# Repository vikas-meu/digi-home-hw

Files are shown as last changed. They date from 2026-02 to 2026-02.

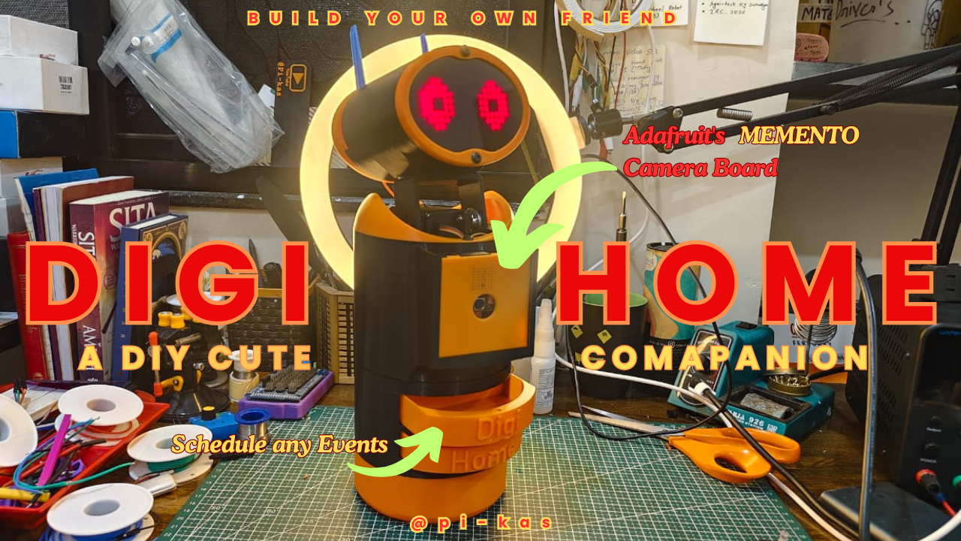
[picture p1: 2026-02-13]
Digi_Home.png

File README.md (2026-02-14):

# 🤖 Digi-Home: Smart Assistant & Memento Board




> **A futuristic, interactive home automation assistant powered by Arduino and ESP32.**  
> *Transform your space with animatronic expressions, IoT control, and automated dispensing.*

---

## 📖 Overview

**Digi-Home** is an integrated ecosystem that combines animatronics, IoT home automation, and interactive robotics. It utilizes a powerful Master-Slave architecture to manage home appliances, provide visual feedback through an animated head, and perform physical tasks like dispensing items.

**(image={System Overview Diagram showing the connections between ESP32, Arduino Base, and Arduino Head})**

### 🚀 Key Features
*   **Animatronic Head**: Expressive 8x8 Matrix eyes and servo-controlled eyelids.
*   **Smart Home Hub**: Web-based control for high-voltage appliances (Lights, Fans).
*   **Automated Dispenser**: Dual servo mechanisms for dispensing tasks.
*   **Interactive Modes**: Includes Dance, Security Sweep, and Sleep modes.

---

## 🛠️ Bill of Materials (BOM)

| Component | Qty | Purchase Link |
| :--- | :---: | :--- |
| **Memento Board By Adafruit** | 1 | [Buy Here](https://www.digikey.in/en/products/detail/adafruit-industries-llc/5420/24713460) |
| **LM2596S DC-DC Buck Converter Power Supply (12v to 5 v)** | 1 | [Buy Here](https://www.google.com/aclk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) |
| **LED 8X8 Matrix** | 2 | [Buy Here](https://www.google.com/aclk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) |
| **MG995 Servo Motor (for Neck)** | 2 | [Buy Here](https://www.google.com/aclk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) |
| **MG90S Servo Motor (for Antenna & Dispensor)** | 4 | [Buy Here](https://www.google.com/aclk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) |
| **Arduino nano (to expand Pins)** | 2 | [Buy Here](https://www.google.com/aclk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) |
| **24 Awg Wires bundle 5 meter** | 1 | [Buy Here](https://www.google.com/aclk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) |
| **eSun PLA+ 1.75mm (Color depends on your Choice)** | 1 | [Buy Here](https://www.google.com/aclk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) |
| **Soldering Iron (Recommended all Tools Are included in this))** | 1 | [Buy Here](https://www.google.com/aclk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) |
| **Glue Gun** | 1 | [Buy Here](https://www.meesho.com/glue-guns/pl/997?srsltid=AfmBOor-x8Y_ux-g0ucn7r0g1IZt1v4XrUss-9I_4eg-g9kcGDKD0NQX) |
| **ESP32 Wroom DA** | 1 | [Buy Here](https://robu.in/product/esp-wroom-32-esp32-wifi-bt-ble-mcu-module/) |
| **4 Channel Relay (5v)** | 1 | [Buy Here](https://www.google.com/aclk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) |
| **li-ion Battery Pack (12v) Recommended** | 1 | [Buy Here](https://www.google.com/aclk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) |
| **Wall Adapter (5V 4amp)** | 1 | [Buy Here](https://www.google.com/aclk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) |
| **Screw Driver Set** | 1 | [Buy Here](https://www.google.com/aclk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) |
| **Wire Cutter** | 1 | [Buy Here](https://kitsguru.com/products/economy-precision-flush-cutter-pcb-wire-nipper-cutting-tool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) |
| **DT830D Multimeter** | 1 | [Buy Here](https://robu.in/product/digital-multimeter-small-yellow-color-lcd-ac-dc-measuring-voltage-current/) |
| **M4x8mm Screws** | 8 | [Buy Here](https://www.google.com/aclk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) |

---

## 📚 Software Infrastructure & Libraries

To compile and upload the code, you **must** install the following libraries in your Arduino IDE.

### 1. Required Libraries
| Library Name | Purpose | Implementation |
| :--- | :--- | :--- |
| **MD_MAX72XX** | Handles the 8x8 LED Matrix display for the eyes. | `head_arduino_0x09.ino` |
| **Servo** | Controls the PWM signals for neck and dispenser motors. | All modules |
| **Wire** | Enables I2C communication between the Master and Slaves. | `Base` & `Head` |
| **WiFi & WebServer** | Enables ESP32 to act as a local IoT server. | `esp32_relay_module.ino` |

### 2. Step-by-Step Installation
1.  Open **Arduino IDE**.
2.  Go to **Tools** -> **Manage Libraries...** 
3.  In the search bar, type `MD_MAX72XX` and click **Install**.
4.  The `Servo`, `Wire`, `WiFi`, and `WebServer` libraries are usually built-in. If missing, search for them individually and install the versions by **Arduino** or **Espressif**.
5.  **ESP32 Board Support**: 
    - Go to `File` -> `Preferences`.
    - In "Additional Boards Manager URLs", paste: `https://raw.githubusercontent.com/espressif/arduino-esp32/gh-pages/package_esp32_index.json`.
    - Go to `Tools` -> `Board` -> `Boards Manager`, search for `esp32` and install.

---

## 🧠 Deep Dive: How the Code Works

The project is split into three core logic modules that communicate over a shared **I2C Bus**.

### 1. Base Controller (`0x08.ino`)
*   **The Logic**: Acts as the "Motor Cortex." It manages physical movement and timing.
*   **Movement Engine**: Uses a smoothing algorithm (`currentPos += (target - currentPos) * 0.1`) to ensure the neck doesn't snap abruptly, creating "alive-like" idle motions.
*   **Dispensing System**: A simple loop blocks I2C for a few seconds during a dispense cycle to ensure mechanical accuracy.

### 2. Head Controller (`0x09.ino`)
*   **The Logic**: Acts as the "Emotional Engine." It translates byte-arrays into facial expressions.
*   **Eye Patterns**: Expressions like `SAD`, `HAPPY`, and `SECURE` are stored as 8-byte hexadecimal arrays. The code updates these columns at high speed to create animations.
*   **Blink Logic**: A randomized timer triggers a "closed eye" pattern for 150ms every 2-5 seconds, simulating human-like behavior.

### 3. ESP32 Relay Module (`esp32_relay.ino`)
*   **The Logic**: Acts as the "Communication Gateway."
*   **REST API**: It maps specific URL paths (like `/light_on`) to GPIO toggles. When you visit the IP address, it serves a lightweight HTML page with buttons that trigger these endpoints.

---

## 🚀 Step-by-Step Setup & Upload

### Phase 1: Preparation
1.  **Wiring**: Connect all SDA pins together and all SCL pins together. Ensure a **Common Ground** between the Nano and ESP32.
2.  **Power**: Plug your 12V battery into the Buck Converter. Tune the converter to exactly **5.0V** before connecting to the Arduinos.

### Phase 2: Uploading Code
1.  **Base (Nano #1)**:
    - Open `Base_trigger.ino`.
    - Select Board: `Arduino Nano` (Processor: `ATmega328P (Old Bootloader)` is common).
    - Upload. Note: This device sits at I2C address `0x08`.
2.  **Head (Nano #2)**:
    - Open `head_arduino_0x09.ino`.
    - Upload to the second Nano. This device sits at I2C address `0x09`.
3.  **IoT Hub (ESP32)**:
    - Open `esp32_relay_module.ino`.
    - **Crucial**: Change lines 4 & 5 to your WiFi Name and Password.
    - Select Board: `ESP32 Dev Module`.
    - Upload. Open the Serial Monitor at 115200 baud to find the **IP Address**.

---

## 🐛 Troubleshooting & Common Errors

### 1. Hardware Issues
*   **"Servos are twitching or the board resets when they move"**
    - **Cause**: Current starvation. Servos can pull 1A+ each when stalled.
    - **Fix**: Use a dedicated 5V 4A supply. Do NOT power servos from the Nano's 5V pin.
*   **"I2C devices not found or data is corrupted"**
    - **Cause**: Missing pull-up resistors or floating ground.
    - **Fix**: Ensure GND is shared. Add two 4.7kΩ resistors between SDA-5V and SCL-5V if the bus is long.

### 2. Software Issues
*   **"Matrix is showing garbage or mirrored text"**
    - **Cause**: Incorrect `HARDWARE_TYPE`.
    - **Fix**: In `head_arduino_0x09.ino`, change `FC16_HW` to `GENERIC_HW` or `ICSTATION_HW` until it looks correct.
*   **"ESP32 won't connect to WiFi"**
    - **Cause**: 5GHz network or wrong credentials.
    - **Fix**: Ensure your router supports 2.4GHz. Triple-check the password in the code.

### 3. Logic Errors
*   **"Dispenser moves but doesn't stop"**
    - **Cause**: Potentiometer setting in MG90S (if modified) or logic interference.
    - **Fix**: Check `DISP_MIN` and `DISP_MAX` values in `Base_trigger.ino`.

---

> **Built with ❤️ for the Memento Board By Adafruit Project**  
> (image={Final assembly photo of the Digi-Home system})

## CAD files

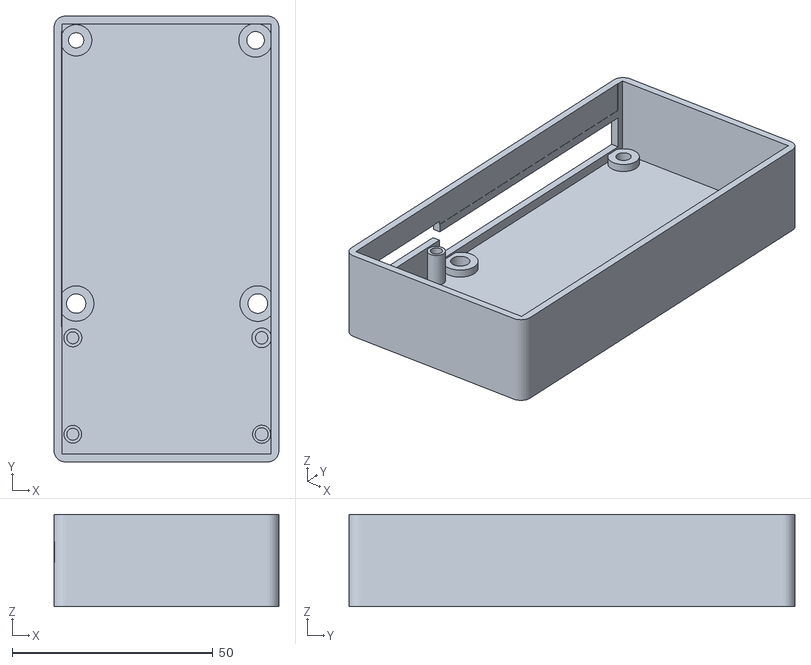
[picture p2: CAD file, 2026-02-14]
3d_files/Optional device cad here/relay_top.stl
56.0 x 111.0 x 23.0

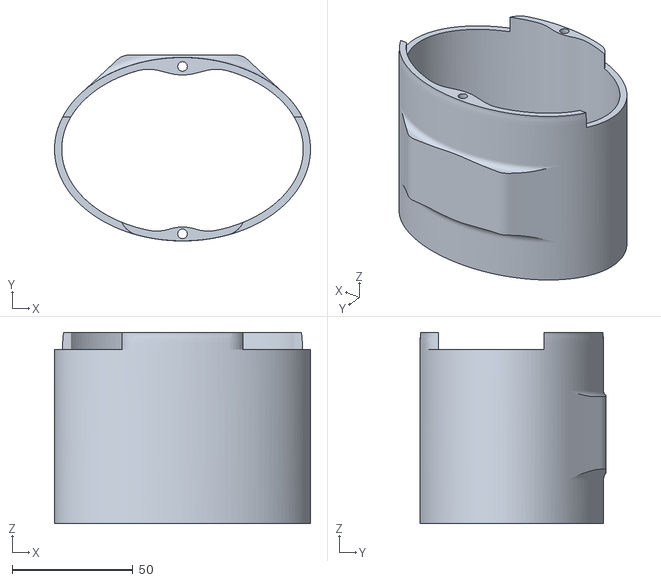
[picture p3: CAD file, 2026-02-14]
3d_files/part1_head_part/b.stl
106.0 x 77.0 x 79.2

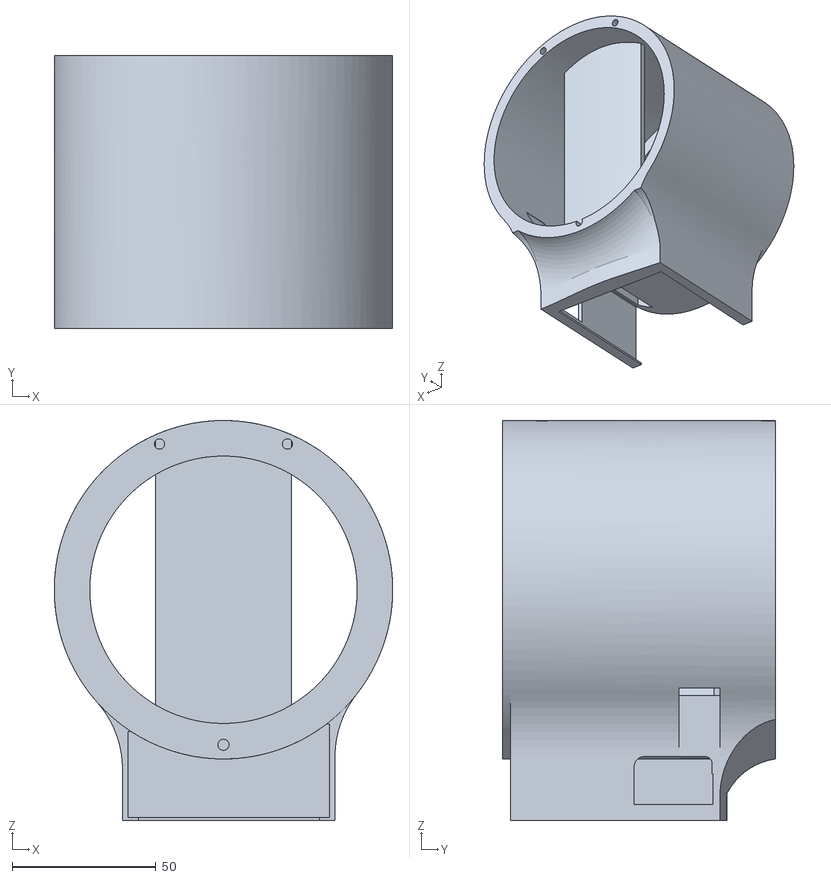
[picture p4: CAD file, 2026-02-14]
3d_files/part2_mid_section/i.stl
117.9 x 95.0 x 139.3

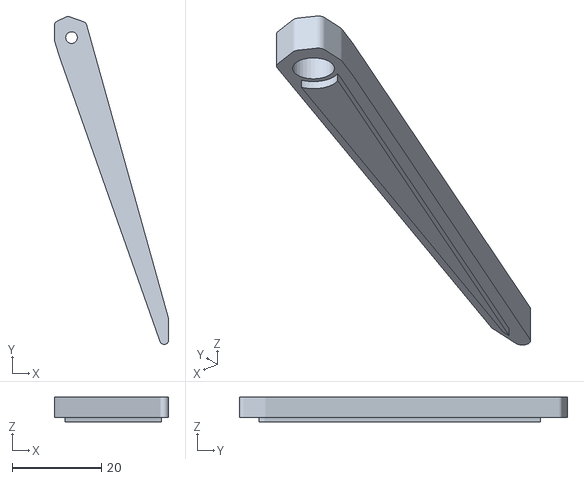
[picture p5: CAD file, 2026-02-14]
3d_files/part3_base_part/antenna_02.stl
25.6 x 73.5 x 5.50

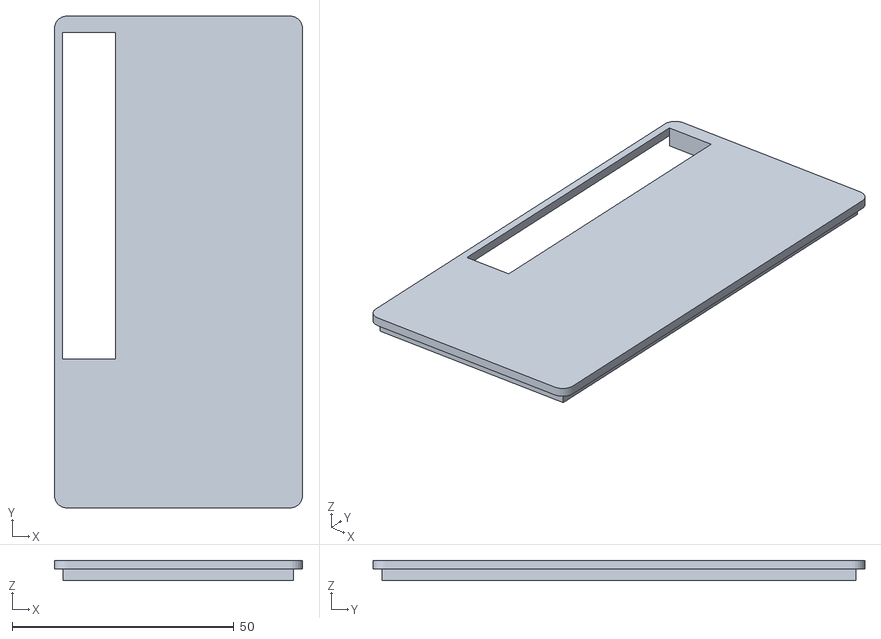
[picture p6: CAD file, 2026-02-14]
3d_files/Optional device cad here/relay_bottom.stl
56.0 x 111.0 x 4.62

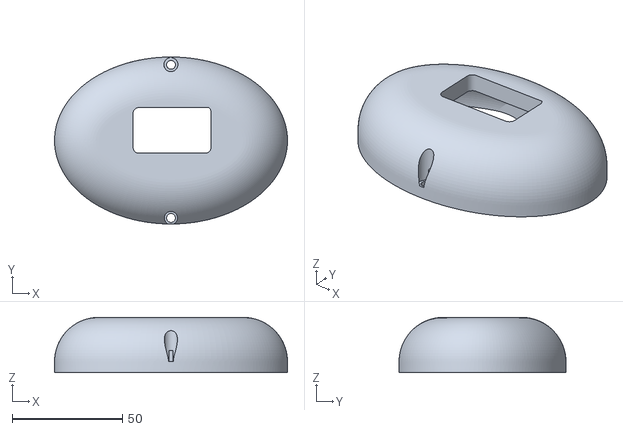
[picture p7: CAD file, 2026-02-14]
3d_files/part1_head_part/c.stl
105.5 x 75.6 x 25.0

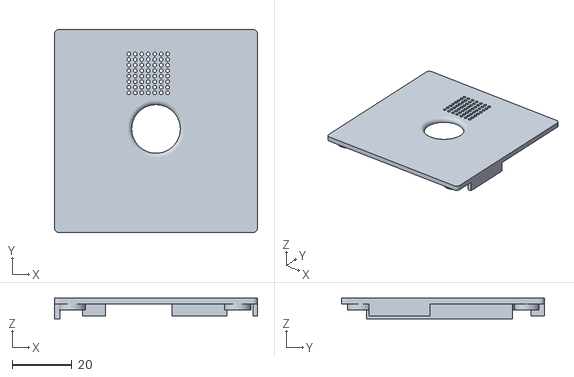
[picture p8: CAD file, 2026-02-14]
3d_files/part2_mid_section/memento_cover_top.stl
68.1 x 68.1 x 7.00

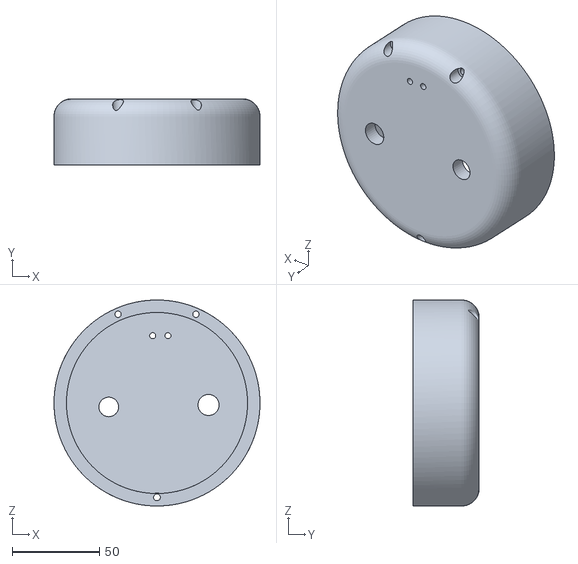
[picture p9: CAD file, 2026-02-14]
3d_files/part3_base_part/l.stl
117.9 x 38.0 x 117.9

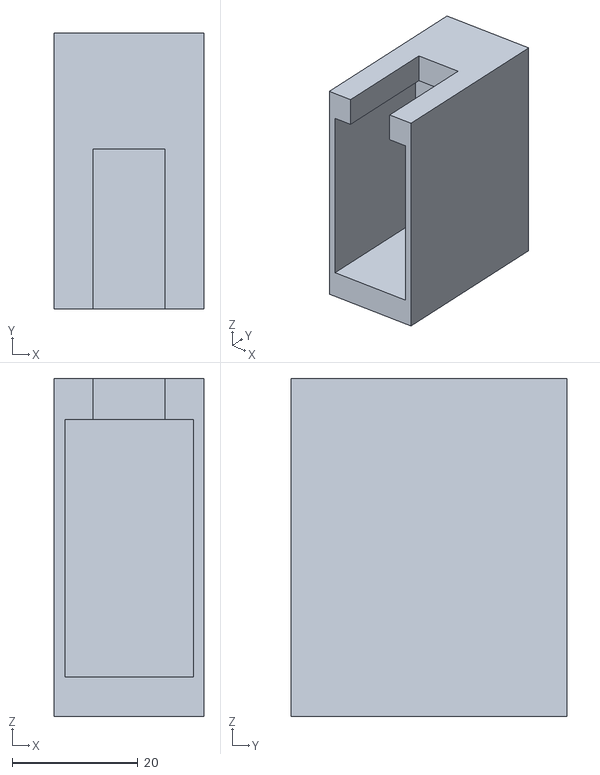
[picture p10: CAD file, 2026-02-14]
3d_files/part1_head_part/g.stl
23.8 x 44.0 x 53.8

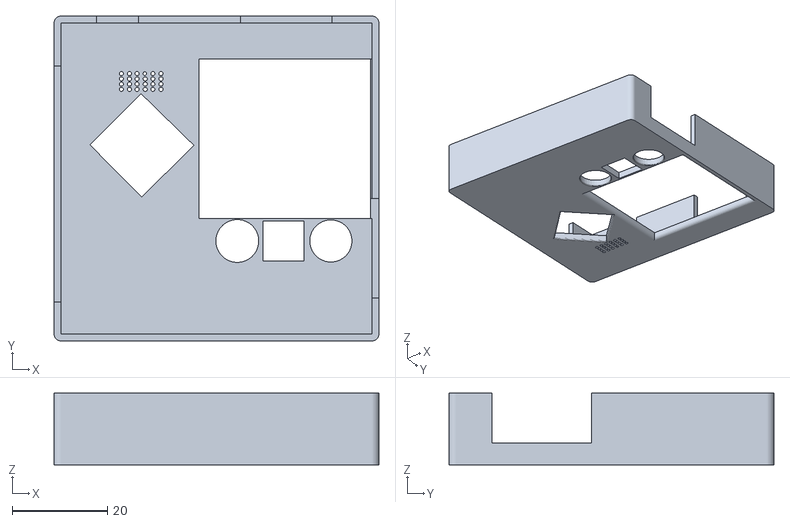
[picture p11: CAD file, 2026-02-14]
3d_files/part2_mid_section/memento_cover_lower.stl
68.1 x 68.1 x 15.0

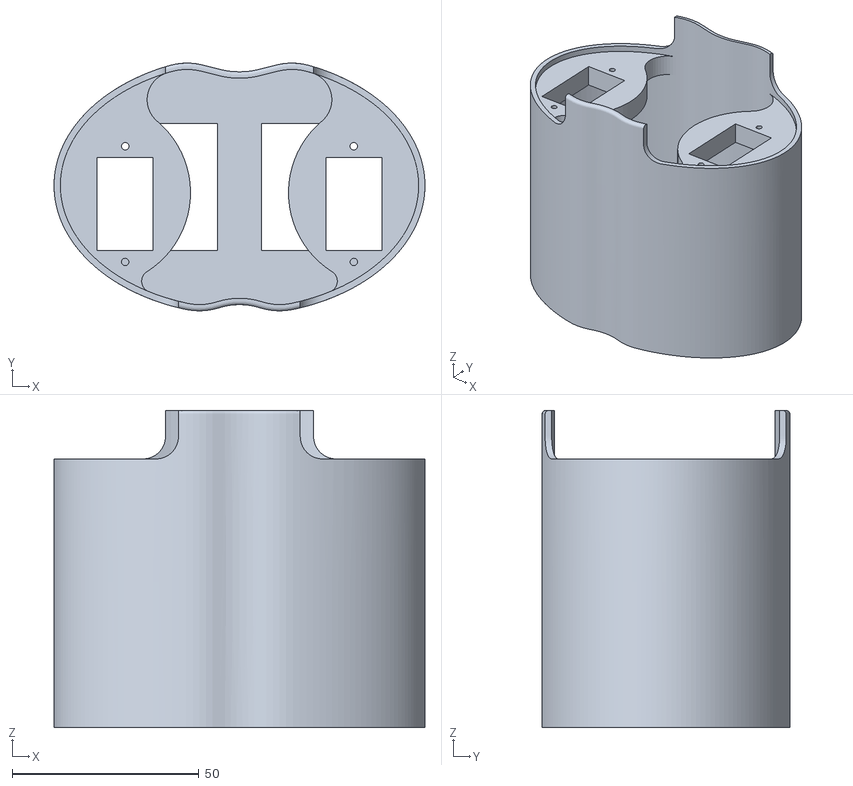
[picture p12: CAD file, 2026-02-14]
3d_files/part1_head_part/f.stl
99.4 x 66.4 x 85.0

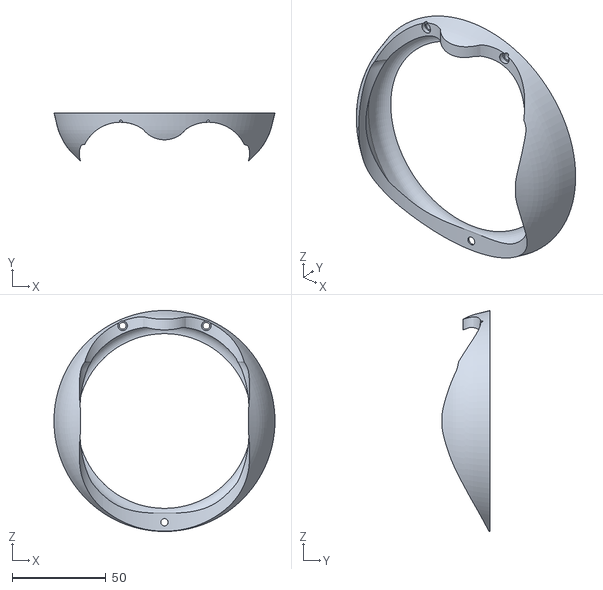
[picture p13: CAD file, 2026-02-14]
3d_files/part2_mid_section/h.stl
117.8 x 25.8 x 117.8

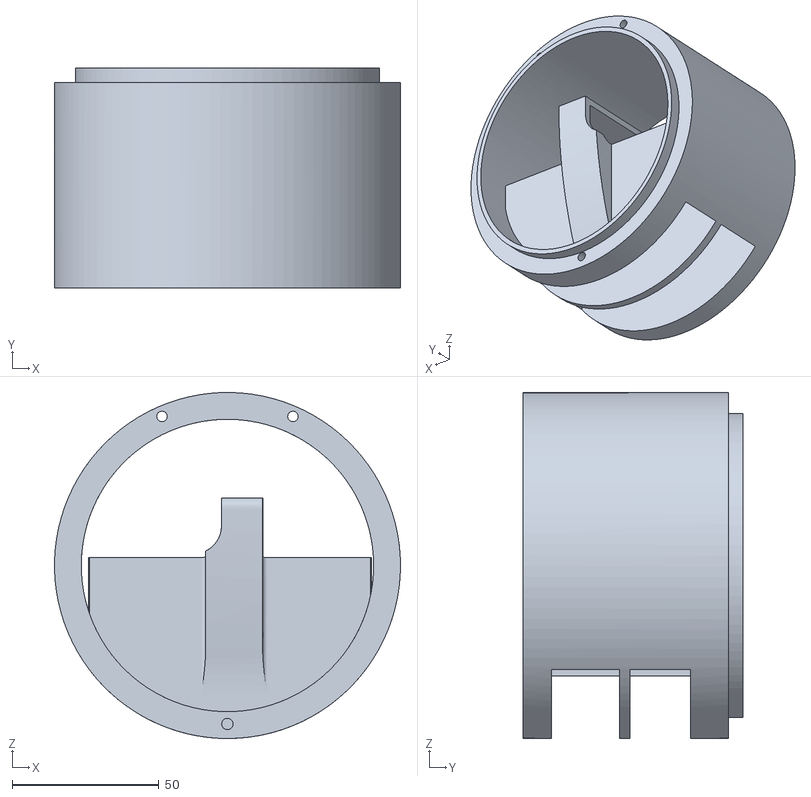
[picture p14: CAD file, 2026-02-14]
3d_files/part3_base_part/m.stl
117.8 x 75.0 x 117.8

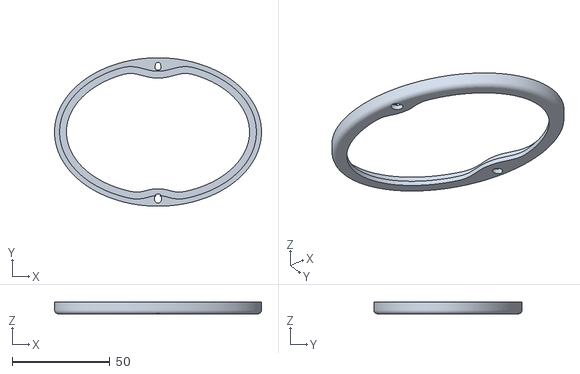
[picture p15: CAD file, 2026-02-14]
3d_files/part1_head_part/a.stl
106.0 x 76.0 x 6.00

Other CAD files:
3d_files/part3_base_part/antenna_01.stl
3d_files/part3_base_part/j.stl
3d_files/part3_base_part/k.stl

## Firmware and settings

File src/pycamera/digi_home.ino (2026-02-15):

/*
 * Copyright (C) 2026-Present Vikash Singh Thakur
 *
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
 * This program is distributed in the hope that it will be useful,
 * but WITHOUT ANY WARRANTY.
 */
#include "Adafruit_PyCamera.h"
#include <Arduino.h>
#include <WiFi.h>
#include <WiFiClientSecure.h>
#include <UniversalTelegramBot.h>
#include <ArduinoJson.h>
#include <SdFat.h> // Already included via Adafruit_PyCamera, but ensure
#include <driver/ledc.h>
#include <driver/gpio.h>
#include <Wire.h>
#include <time.h>
#include <WiFiUdp.h>
#include <NTPClient.h>
#include <vector>
#include <strings.h>
#include <esp_camera.h>
// --- CREDENTIALS ---
const char* ssid = " ";
const char* password = " ";
#define BOTtoken " "
#define CHAT_ID " "
// Pin definitions
#define MIC 20
#define SPEAKER 18
#define AWEXP_SPKR_SD 0 // Speaker mute control on AW9523 pin 0
#define SDA_PIN 34
#define SCL_PIN 33
// I2C slave address for Arduino
const uint8_t ARDUINO_ADDR = 0x08;
const uint8_t ARDUINO2_ADDR = 0x09; // Second Arduino
// Timezone offset for IST (UTC+5:30)
const long timezoneOffset = 19800; // 5.5 * 3600
// Controller ESP32 IP (replace with the actual IP of the ESP32 running the web server)
const char* controllerIP = "192.168.1.100"; // TODO: Set to the IP address of the control ESP32
Adafruit_PyCamera pycamera;
WiFiClientSecure client;
UniversalTelegramBot bot(BOTtoken, client);
// Global variables for the "chunked" upload
int currentByte = 0;
size_t fb_length = 0;
uint8_t* fb_buffer = NULL;
// Helper functions for Telegram binary transfer
bool isMoreDataAvailable() {
  return (fb_length - currentByte);
}
uint8_t photoNextByte() {
  currentByte++;
  return fb_buffer[currentByte - 1];
}
// For Telegram polling
unsigned long bot_lasttime = 0;
const long BOT_MTBS = 2000; // Poll every 1 second
// For motion detection
uint16_t *prev_buffer = NULL;
unsigned long last_snap_time = 0;
const long SNAP_COOLDOWN = 5000; // 5 seconds cooldown to avoid spamming
bool securityMode = false;
// For green object tracking
bool tracking = false;
// For scheduling
struct Event {
  time_t eventTime;
  String details;
  String arduinoCmd;
  String reminder;
  bool triggered = false;
};
std::vector<Event> scheduledEvents;
bool awaitingSchedule = false;
// Modes
enum Mode {
  MODE_IDLE,
  MODE_MENU,
  MODE_CAMERA,
  MODE_GAME_MENU,
  MODE_PINGPONG,
  MODE_SNAKE,
  MODE_HOME_ASSISTANT
};
Mode currentMode = MODE_IDLE;
int menuSelection = 0;
const char* menuOptions[] = {"Camera Mode", "Game Mode", "Home Assistant"};
int numMenuOptions = sizeof(menuOptions) / sizeof(menuOptions[0]);
// For games
// Snake game variables
#define SNAKE_MAX_LENGTH 100
struct Point {
  int x, y;
};
Point snake[SNAKE_MAX_LENGTH];
int snakeLength = 5;
int snakeDir = 0; // 0 right, 1 down, 2 left, 3 up
Point food;
unsigned long lastSnakeMove = 0;
int snakeSpeed = 200;
// Pong game variables
int paddle1Y = 100, paddle2Y = 100;
int ballX = 120, ballY = 120;
int ballDX = 2, ballDY = 2;
int score1 = 0, score2 = 0;
unsigned long lastPongUpdate = 0;
int pongSpeed = 10;
// For game submenu
const char* gameOptions[] = {"Ping Pong", "Snake"};
int numGameOptions = 2;
int gameSelection = 0;
// Function prototypes
void drawMenu();
void handleMenuNavigation();
void cameraMode();
void pingPongMode();
void snakeMode();
void homeAssistantMode();
void handleNewMessages(int numNewMessages);
void takeAndSendPhoto(int reply_to_message_id = 0);
void recordAudio();
void playAudio();
void sendDanceCommand();
void trackGreenObject();
void checkScheduledEvents();
bool parseSchedule(String text, String chat_id);
void sendI2CCommandTo(uint8_t addr, const char* cmd);
void sendTelegramMessage(String chat_id, String message, int reply_to_message_id = 0);
void sendControlCommand(String endpoint);
void setup() {
  Serial.begin(115200);
  delay(100);
  if (!pycamera.begin()) {
    Serial.println("Failed to initialize pyCamera interface");
    while (1) yield();
  }
  Serial.println("pyCamera hardware initialized!");
  pycamera.initSD();
  // Initialize snake
  for (int i = 0; i < snakeLength; i++) {
    snake[i].x = 120 - i*10;
    snake[i].y = 120;
  }
  food.x = random(24)*10;
  food.y = random(24)*10;
  pycamera.photoSize = FRAMESIZE_QVGA;
  if (!pycamera.initSD()) {
    Serial.println("SD init failed!");
    while (1);
  }
  // Allocate previous buffer for motion detection (240x240 RGB565)
  prev_buffer = (uint16_t*)ps_malloc(240 * 240 * sizeof(uint16_t));
  if (!prev_buffer) {
    Serial.println("Failed to allocate prev_buffer!");
    while (1);
  }
  WiFi.begin(ssid, password);
  client.setInsecure();
  while (WiFi.status() != WL_CONNECTED) { delay(500); Serial.print("."); }
  Serial.println("\nReady!");
  // Set up time
  configTime(timezoneOffset, 0, "pool.ntp.org", "time.nist.gov");
  struct tm timeinfo;
  if (!getLocalTime(&timeinfo)) {
    Serial.println("Failed to obtain time");
  }
  // Initialize display settings for the Gyro text
  pycamera.fb->setTextSize(2);
  // Setup LEDC timer
  ledc_timer_config_t timer_conf = {
      .speed_mode = LEDC_LOW_SPEED_MODE,
      .duty_resolution = LEDC_TIMER_8_BIT,
      .timer_num = LEDC_TIMER_0,
      .freq_hz = 200000,
      .clk_cfg = LEDC_AUTO_CLK
  };
  ESP_ERROR_CHECK(ledc_timer_config(&timer_conf));
  // Initialize I2C as master
  Wire.begin(SDA_PIN, SCL_PIN);

  // Start in Home Assistant mode by default
  currentMode = MODE_HOME_ASSISTANT;
}
void loop() {
  pycamera.readButtons();
  if (pycamera.justPressed(AWEXP_BUTTON_SEL)) {
    if (currentMode != MODE_MENU) {
      currentMode = MODE_MENU;
      menuSelection = 0;
      drawMenu();
    }
  }
  switch (currentMode) {
    case MODE_MENU:
      handleMenuNavigation();
      break;
    case MODE_CAMERA:
      cameraMode();
      break;
    case MODE_GAME_MENU:
      // Similar to menu
      if (pycamera.justPressed(AWEXP_BUTTON_UP)) gameSelection = (gameSelection - 1 + numGameOptions) % numGameOptions;
      if (pycamera.justPressed(AWEXP_BUTTON_DOWN)) gameSelection = (gameSelection + 1) % numGameOptions;
      if (pycamera.justPressed(AWEXP_BUTTON_OK)) {
        if (gameSelection == 0) currentMode = MODE_PINGPONG;
        else currentMode = MODE_SNAKE;
      }
      // Draw game menu
      pycamera.fb->fillScreen(0);
      pycamera.fb->setCursor(10, 10);
      pycamera.fb->setTextSize(2);
      pycamera.fb->print("Games:");
      for (int i = 0; i < numGameOptions; i++) {
        pycamera.fb->setCursor(10, 40 + i*20);
        if (i == gameSelection) pycamera.fb->setTextColor(0xFFFF);
        else pycamera.fb->setTextColor(0xAD55);
        pycamera.fb->print(gameOptions[i]);
      }
      pycamera.blitFrame();
      break;
    case MODE_PINGPONG:
      pingPongMode();
      break;
    case MODE_SNAKE:
      snakeMode();
      break;
    case MODE_HOME_ASSISTANT:
      homeAssistantMode();
      break;
    default:
      // Idle: perhaps live preview
      pycamera.captureFrame();
      pycamera.blitFrame();
      break;
  }
  delay(10);
}
// Draw main menu
void drawMenu() {
  pycamera.fb->fillScreen(0);
  pycamera.fb->setCursor(10, 10);
  pycamera.fb->setTextSize(2);
  pycamera.fb->setTextColor(0xFFFF);
  pycamera.fb->print("Menu:");
  for (int i = 0; i < numMenuOptions; i++) {
    pycamera.fb->setCursor(10, 40 + i*20);
    if (i == menuSelection) pycamera.fb->setTextColor(0xFFFF);
    else pycamera.fb->setTextColor(0xAD55);
    pycamera.fb->print(menuOptions[i]);
  }
  pycamera.blitFrame();
}
// Handle navigation in menu
void handleMenuNavigation() {
  if (pycamera.justPressed(AWEXP_BUTTON_UP)) {
    menuSelection = (menuSelection - 1 + numMenuOptions) % numMenuOptions;
    drawMenu();
  }
  if (pycamera.justPressed(AWEXP_BUTTON_DOWN)) {
    menuSelection = (menuSelection + 1) % numMenuOptions;
    drawMenu();
  }
  if (pycamera.justPressed(AWEXP_BUTTON_OK)) {
    switch (menuSelection) {
      case 0: currentMode = MODE_CAMERA; break;
      case 1: currentMode = MODE_GAME_MENU; gameSelection = 0; break;
      case 2: currentMode = MODE_HOME_ASSISTANT; break;
    }
  }
}
// Camera mode
void cameraMode() {
  pycamera.captureFrame();
  // Add UI if needed
  pycamera.fb->setCursor(10, 10);
  pycamera.fb->setTextSize(1);
  pycamera.fb->print("Camera Mode");
  pycamera.blitFrame();
  if (pycamera.justPressed(SHUTTER_BUTTON)) {
    pycamera.takePhoto("PHOTO", pycamera.photoSize);
    pycamera.speaker_tone(100, 50);
  }
  if (pycamera.justPressed(AWEXP_BUTTON_UP)) pycamera.photoSize = (framesize_t)((int)pycamera.photoSize + 1 % 11);
  if (pycamera.justPressed(AWEXP_BUTTON_DOWN)) pycamera.photoSize = (framesize_t)((int)pycamera.photoSize - 1 + 11 % 11);
  if (pycamera.justPressed(AWEXP_BUTTON_LEFT)) pycamera.specialEffect = (pycamera.specialEffect + 6) % 7; pycamera.setSpecialEffect(pycamera.specialEffect);
  if (pycamera.justPressed(AWEXP_BUTTON_RIGHT)) pycamera.specialEffect = (pycamera.specialEffect + 1) % 7; pycamera.setSpecialEffect(pycamera.specialEffect);
}
// Ping Pong mode (simple AI for player 2)
void pingPongMode() {
  if (millis() - lastPongUpdate > pongSpeed) {
    lastPongUpdate = millis();
    // Move paddles
    if (pycamera.justPressed(AWEXP_BUTTON_UP)) paddle1Y -= 10;
    if (pycamera.justPressed(AWEXP_BUTTON_DOWN)) paddle1Y += 10;
    paddle1Y = constrain(paddle1Y, 0, 200);
    // AI for paddle2
    if (ballY > paddle2Y + 20) paddle2Y += 4;
    if (ballY < paddle2Y) paddle2Y -= 4;
    paddle2Y = constrain(paddle2Y, 0, 200);
    // Move ball
    ballX += ballDX;
    ballY += ballDY;
    // Bounce walls
    if (ballY <= 0 || ballY >= 240) ballDY = -ballDY;
    // Bounce paddles
    if (ballX <= 10 && ballY > paddle1Y && ballY < paddle1Y + 40) ballDX = -ballDX;
    if (ballX >= 230 && ballY > paddle2Y && ballY < paddle2Y + 40) ballDX = -ballDX;
    // Score
    if (ballX < 0) { score2++; ballX = 120; ballY = 120; ballDX = 2; }
    if (ballX > 240) { score1++; ballX = 120; ballY = 120; ballDX = -2; }
  }
  // Draw
  pycamera.fb->fillScreen(0);
  // Paddles
  pycamera.fb->fillRect(5, paddle1Y, 5, 40, 0xFFFF);
  pycamera.fb->fillRect(230, paddle2Y, 5, 40, 0xFFFF);
  // Ball
  pycamera.fb->fillRect(ballX, ballY, 5, 5, 0xFFFF);
  // Scores
  pycamera.fb->setCursor(50, 10);
  pycamera.fb->print(score1);
  pycamera.fb->setCursor(180, 10);
  pycamera.fb->print(score2);
  pycamera.blitFrame();
  if (pycamera.justPressed(AWEXP_BUTTON_SEL)) currentMode = MODE_MENU; // Exit
}
// Snake mode
void snakeMode() {
  if (millis() - lastSnakeMove > snakeSpeed) {
    lastSnakeMove = millis();
    // Move snake
    for (int i = snakeLength - 1; i > 0; i--) {
      snake[i] = snake[i-1];
    }
    if (snakeDir == 0) snake[0].x += 10;
    if (snakeDir == 1) snake[0].y += 10;
    if (snakeDir == 2) snake[0].x -= 10;
    if (snakeDir == 3) snake[0].y -= 10;
    // Wrap around
    if (snake[0].x >= 240) snake[0].x = 0;
    if (snake[0].x < 0) snake[0].x = 240;
    if (snake[0].y >= 240) snake[0].y = 0;
    if (snake[0].y < 0) snake[0].y = 240;
    // Eat food
    if (snake[0].x == food.x && snake[0].y == food.y) {
      snakeLength++;
      food.x = random(24)*10;
      food.y = random(24)*10;
      pycamera.speaker_tone(440, 50);
    }
    // Collision with self
    for (int i = 1; i < snakeLength; i++) {
      if (snake[0].x == snake[i].x && snake[0].y == snake[i].y) {
        snakeLength = 5; // Reset
        pycamera.speaker_tone(100, 200);
      }
    }
  }
  // Controls
  if (pycamera.justPressed(AWEXP_BUTTON_RIGHT)) snakeDir = 0;
  if (pycamera.justPressed(AWEXP_BUTTON_DOWN)) snakeDir = 1;
  if (pycamera.justPressed(AWEXP_BUTTON_LEFT)) snakeDir = 2;
  if (pycamera.justPressed(AWEXP_BUTTON_UP)) snakeDir = 3;
  // Draw
  pycamera.fb->fillScreen(0);
  for (int i = 0; i < snakeLength; i++) {
    pycamera.fb->fillRect(snake[i].x, snake[i].y, 10, 10, 0x07E0);
  }
  pycamera.fb->fillRect(food.x, food.y, 10, 10, 0xF800);
  pycamera.fb->setCursor(10, 10);
  pycamera.fb->print("Length: "); pycamera.fb->print(snakeLength);
  pycamera.blitFrame();
  if (pycamera.justPressed(AWEXP_BUTTON_SEL)) currentMode = MODE_MENU;
}
// Home Assistant placeholder
void homeAssistantMode() {
  pycamera.captureFrame();
  // Motion detection only in security mode
  if (securityMode && prev_buffer) {
    uint16_t *curr = (uint16_t *)pycamera.fb->getBuffer();
    long total_diff = 0;
    long sum_x = 0;
    long sum_y = 0;
    int step = 2; // Subsample for efficiency (balance speed and accuracy)
    int pix_threshold = 20; // Lowered from 30 for better sensitivity
    for (int y = 0; y < 240; y += step) {
      for (int x = 0; x < 240; x += step) {
        uint16_t p1 = prev_buffer[y * 240 + x];
        uint16_t p2 = curr[y * 240 + x];
        int r1 = (p1 >> 11) & 0x1F;
        int g1 = (p1 >> 5) & 0x3F;
        int b1 = p1 & 0x1F;
        int r2 = (p2 >> 11) & 0x1F;
        int g2 = (p2 >> 5) & 0x3F;
        int b2 = p2 & 0x1F;
        int pix_diff = abs(r1 - r2) + abs(g1 - g2) + abs(b1 - b2);
        if (pix_diff > pix_threshold) {
          sum_x += (long)x * pix_diff;
          sum_y += (long)y * pix_diff;
          total_diff += pix_diff;
        }
      }
    }
    int num_pixels = (240 / step) * (240 / step);
    float avg_diff = (float)total_diff / (num_pixels * 3.0 * 31.0); // Normalized (adjust threshold as needed)
    Serial.printf("Average diff: %.2f\n", avg_diff); // Added for debugging
    if (total_diff > 0) {
      int cx = sum_x / total_diff;
      int cy = sum_y / total_diff;
      Serial.printf("Motion blob center at (%d, %d)\n", cx, cy);
    }
    if (avg_diff > 0.05 && (millis() - last_snap_time > SNAP_COOLDOWN)) { // Lowered threshold from 0.2 for better sensitivity
      Serial.println("High motion detected! Taking snapshot...");
      sendI2CCommandTo(ARDUINO_ADDR, "High motion detected! Taking snapshot...");
      takeAndSendPhoto(0);
      last_snap_time = millis();
    }
  }
  memcpy(prev_buffer, pycamera.fb->getBuffer(), 240 * 240 * sizeof(uint16_t));
  // --- LIVE GYRO DATA DISPLAY ---
  float x, y, z;
  if (pycamera.readAccelData(&x, &y, &z)) {
    // Positioning text at the top of the frame
    Serial.printf("ACCEL: X=%0.2f, Y=%0.2f, Z=%0.2f\n", x, y, z);
    pycamera.fb->setCursor(10, 10);
    pycamera.fb->setTextColor(0x780F); // Your favorite Purple color!
    pycamera.fb->printf("X:%0.1f Y:%0.1f Z:%0.1f", x, y, z);
  }
  // Green object tracking if enabled
  if (tracking) {
    trackGreenObject();
  }
  // Check scheduled events
  checkScheduledEvents();
  // Trigger snapshot with the Shutter button
  if (pycamera.justPressed(SHUTTER_BUTTON)) {
    Serial.println("Taking Snapshot...");
    takeAndSendPhoto(0);
  }
  // Check for serial commands
  if (Serial.available()) {
    String cmd = Serial.readStringUntil('\n');
    cmd.trim();
    if (cmd == "snap") {
      Serial.println("Serial snap command received!");
      takeAndSendPhoto(0);
    }
  }
  // Poll Telegram for new messages
  if (millis() - bot_lasttime > BOT_MTBS) {
    int numNewMessages = bot.getUpdates(bot.last_message_received + 1);
    handleNewMessages(numNewMessages);
    bot_lasttime = millis();
  }
  pycamera.blitFrame();
  if (pycamera.justPressed(AWEXP_BUTTON_SEL)) currentMode = MODE_MENU;
}
void sendI2CCommandTo(uint8_t addr, const char* cmd) {
  Wire.beginTransmission(addr);
  Wire.write((const uint8_t*)cmd, strlen(cmd));
  Wire.endTransmission();
}
// Helper function to send Telegram messages
// Centralizes bot.sendMessage calls for easy parameter modification
void sendTelegramMessage(String chat_id, String message, int reply_to_message_id) {
  bot.sendMessage(chat_id, message, "", 0, reply_to_message_id);
}
void checkScheduledEvents() {
  time_t now = time(nullptr);
  for (auto it = scheduledEvents.begin(); it != scheduledEvents.end(); ) {
    if (now >= it->eventTime && !it->triggered) {
      if (it->arduinoCmd != "none") {
        sendI2CCommandTo(ARDUINO_ADDR, it->arduinoCmd.c_str());
        Serial.printf("Sent command '%s' to Arduino\n", it->arduinoCmd.c_str());
      }
      if (!it->reminder.isEmpty()) {
        sendTelegramMessage(CHAT_ID, it->reminder);
      }
      it->triggered = true;
      it = scheduledEvents.erase(it); // Remove after trigger
    } else {
      ++it;
    }
  }
}
bool parseSchedule(String text, String chat_id) {
  // Split by lines
  String lines[5];
  int idx = 0;
  int pos = 0;
  while (idx < 5) {
    int nl = text.indexOf('\n', pos);
    if (nl == -1) {
      lines[idx] = text.substring(pos);
      break;
    }
    lines[idx] = text.substring(pos, nl);
    pos = nl + 1;
    idx++;
  }
  String timeStr, dateStr, details, arduinoCmd, reminder;
  for (int i = 0; i <= idx; i++) {
    String line = lines[i];
    line.trim();
    if (line.startsWith("Time:")) {
      timeStr = line.substring(5);
      timeStr.trim();
    } else if (line.startsWith("Date:")) {
      dateStr = line.substring(5);
      dateStr.trim();
    } else if (line.startsWith("Details:")) {
      details = line.substring(8);
      details.trim();
    } else if (line.startsWith("Command:")) {
      arduinoCmd = line.substring(8);
      arduinoCmd.trim();
    } else if (line.startsWith("Reminder:")) {
      reminder = line.substring(9);
      reminder.trim();
    }
  }
  if (timeStr.isEmpty() || dateStr.isEmpty()) {
    return false;
  }
  // Parse date and time - support both MM/DD/YYYY and DD/MM/YYYY
  struct tm tm = {0};
  int day, month, year;
  if (sscanf(dateStr.c_str(), "%d/%d/%d", &month, &day, &year) != 3) {
    return false;
  }
  tm.tm_year = year - 1900;
  tm.tm_mon = month - 1;
  tm.tm_mday = day;
  int hour, min;
  char ampm[3];
  if (sscanf(timeStr.c_str(), "%d:%d %2s", &hour, &min, ampm) != 3) {
    return false;
  }
  if (strcasecmp(ampm, "pm") == 0 && hour < 12) hour += 12;
  else if (strcasecmp(ampm, "am") == 0 && hour == 12) hour = 0;
  tm.tm_hour = hour;
  tm.tm_min = min;
  tm.tm_sec = 0;
  time_t eventTime = mktime(&tm);
  Event ev;
  ev.eventTime = eventTime;
  ev.details = details;
  ev.arduinoCmd = arduinoCmd;
  ev.reminder = reminder;
  scheduledEvents.push_back(ev);
  return true;
}
void trackGreenObject() {
  uint16_t *fb = (uint16_t *)pycamera.fb->getBuffer();
  int minx = 239, maxx = 0, miny = 239, maxy = 0;
  bool found = false;
  for (int y = 0; y < 240; y++) {
    for (int x = 0; x < 240; x++) {
      uint16_t pix = fb[y * 240 + x];
      uint8_t r = ((pix >> 11) & 0x1F) << 3;
      uint8_t g = ((pix >> 5) & 0x3F) << 2;
      uint8_t b = (pix & 0x1F) << 3;
      // Green detection threshold (adjust as needed)
      if (g > 100 && g > r + 50 && g > b + 50) {
        found = true;
        if (x < minx) minx = x;
        if (x > maxx) maxx = x;
        if (y < miny) miny = y;
        if (y > maxy) maxy = y;
      }
    }
  }
  if (found && (maxx - minx > 10) && (maxy - miny > 10)) {
    int cx = (minx + maxx) / 2;
    int cy = (miny + maxy) / 2;
    // Draw bounding box (red)
    pycamera.fb->drawRect(minx, miny, maxx - minx + 1, maxy - miny + 1, 0xF800);
    // Send position to Arduino via I2C
    Wire.beginTransmission(ARDUINO_ADDR);
    Wire.write((uint8_t)cx);
    Wire.write((uint8_t)cy);
    Wire.endTransmission();
    Serial.printf("Green object at (%d, %d)\n", cx, cy);
  }
}
void sendDanceCommand() {
  sendI2CCommandTo(ARDUINO_ADDR, "dance");
  Serial.println("Sent 'dance' command to Arduino");
}
void takeAndSendPhoto(int reply_to_message_id) {
  pycamera.setNeopixel(0x800080); // Purple flash
  camera_fb_t * fb = esp_camera_fb_get();
  if (!fb) {
    Serial.println("Camera capture failed");
    if (reply_to_message_id != 0) {
      sendTelegramMessage(CHAT_ID, "❌ Camera capture failed!", reply_to_message_id);
    }
    return;
  }
  fb_length = fb->len;
  fb_buffer = fb->buf;
  currentByte = 0;
  Serial.println("Sending to Telegram...");
  // Note: UniversalTelegramBot's sendPhotoByBinary doesn't support reply_to_message_id directly
  // The photo itself won't be a reply, but we send a confirmation message as a reply
  if (bot.sendPhotoByBinary(CHAT_ID, "image/jpeg", fb->len,
                            isMoreDataAvailable, photoNextByte,
                            nullptr, nullptr)) {
    Serial.println("Photo sent successfully!");
    if (reply_to_message_id != 0) {
      sendTelegramMessage(CHAT_ID, "✅ Photo captured and sent!", reply_to_message_id);
    }
  } else {
    Serial.println("Telegram upload failed.");
    if (reply_to_message_id != 0) {
      sendTelegramMessage(CHAT_ID, "❌ Failed to send photo!", reply_to_message_id);
    }
  }
  esp_camera_fb_return(fb);
  pycamera.setNeopixel(0x000000);
}
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

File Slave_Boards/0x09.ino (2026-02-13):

#include <MD_MAX72xx.h>
#include <SPI.h>
#include <Servo.h>
#include <Wire.h>

// ================= I2C ADDRESS =================
#define I2C_ADDR 0x09

// ================= LED MATRIX =================
#define HARDWARE_TYPE MD_MAX72XX::FC16_HW
#define MAX_DEVICES 4
#define CS_PIN 10
MD_MAX72XX mx = MD_MAX72XX(HARDWARE_TYPE, CS_PIN, MAX_DEVICES);

// ================= SERVOS =================
#define LEFT_SERVO_PIN 6
#define RIGHT_SERVO_PIN 3
Servo leftServo;
Servo rightServo;
int currentPos = 45;

// ================= MODES =================
enum Mode {
  MODE_DEFAULT,
  MODE_SAD,
  MODE_HAPPY,
  MODE_SLEEP,
  MODE_SECURE
};

Mode currentMode = MODE_DEFAULT;
bool servoEnabled = true;
unsigned long sleepStartTime = 0;
bool sleepMessageShown = false;

// ================= EYE PATTERNS =================

// OPEN
const uint8_t eye_open[8] = {
  0b00000000,
  0b00111100,
  0b01111110,
  0b11100111,
  0b11100111,
  0b01111110,
  0b00111100,
  0b00000000
};

// SAD (drooping bottom)
const uint8_t eye_sad[8] = {
  0b00000111,
  0b00001110,
  0b00111000,
  0b00011100,
  0b00001110,
  0b00011100,
  0b00111000,
  0b01100000
};

// HAPPY (bigger arc)
const uint8_t eye_happy[8] = {
  0b00000000,
  0b00000000,
  0b01111110,
  0b11111111,
  0b11111111,
  0b01111110,
  0b00000000,
  0b00000000
};

// CLOSED
const uint8_t eye_closed[8] = {
  0b00011000,
  0b00011000,
  0b00011000,
  0b00011000,
  0b00011000,
  0b00011000,
  0b00011000,
  0b00011000
};

// SECURE (circle + center dot)
const uint8_t eye_secure[8] = {
  0b00000000,
  0b00111100,
  0b01100110,
  0b10011001,
  0b10011001,
  0b01100110,
  0b00111100,
  0b00000000
};

// ================= SETUP =================
void setup() {
  mx.begin();
  mx.clear();
  mx.control(MD_MAX72XX::INTENSITY, 4);

  randomSeed(analogRead(0));
  Serial.begin(115200);

  leftServo.attach(LEFT_SERVO_PIN);
  rightServo.attach(RIGHT_SERVO_PIN);
  leftServo.write(currentPos);
  rightServo.write(90 - currentPos);

  // I2C SLAVE START
  Wire.begin(I2C_ADDR);
  Wire.onReceive(receiveEvent);

  Serial.println("Robot Eyes Ready (I2C 0x09)");
}

// ================= DISPLAY =================
void displayEyes(const uint8_t *pattern) {
  mx.clear();
  for (uint8_t col = 0; col < 8; col++) {
    mx.setColumn(col, pattern[col]);
    mx.setColumn(col + 24, pattern[col]);
  }
  mx.update();
}

// ================= SERVO =================
void smoothMove(int targetPos) {
  if (!servoEnabled) return;

  int step = (targetPos > currentPos) ? 1 : -1;
  while (currentPos != targetPos) {
    currentPos += step;
    leftServo.write(currentPos);
    rightServo.write(90 - currentPos);
    delay(15);
  }
}

// ================= COMMAND HANDLER =================
void handleCommand(String cmd) {
  cmd.trim();

  if (cmd == "exp1") {
    currentMode = MODE_SAD;
  }
  else if (cmd == "exp2") {
    currentMode = MODE_HAPPY;
  }
  else if (cmd == "sleep") {
    currentMode = MODE_SLEEP;
    servoEnabled = false;
    sleepStartTime = millis();
    sleepMessageShown = false;
  }
  else if (cmd == "secure") {
    currentMode = MODE_SECURE;
    servoEnabled = false;
  }
  else if (cmd == "wake") {
    currentMode = MODE_DEFAULT;
    servoEnabled = true;
    mx.control(MD_MAX72XX::SHUTDOWN, false);
  }
}

// ================= I2C RECEIVE =================
void receiveEvent(int howMany) {
  String received = "";
  while (Wire.available()) {
    char c = Wire.read();
    received += c;
  }
  handleCommand(received);
}

// ================= LOOP =================
unsigned long lastBlinkTime = 0;
unsigned long lastServoTime = 0;

void loop() {

  // SERIAL COMMAND SUPPORT
  if (Serial.available()) {
    String cmd = Serial.readStringUntil('\n');
    handleCommand(cmd);
  }

  switch (currentMode) {

    case MODE_DEFAULT:
      displayEyes(eye_open);

      if (millis() - lastBlinkTime > random(2000, 5000)) {
        displayEyes(eye_closed);
        delay(150);
        displayEyes(eye_open);
        lastBlinkTime = millis();
      }

      if (millis() - lastServoTime > random(1000, 5000)) {
        smoothMove(random(0, 91));
        lastServoTime = millis();
      }
      break;

    case MODE_SAD:
      displayEyes(eye_sad);
      break;

    case MODE_HAPPY:
      displayEyes(eye_happy);
      break;

    case MODE_SLEEP:
      displayEyes(eye_closed);

      if (!sleepMessageShown && millis() - sleepStartTime > 10000) {
        Serial.println("Going to sleep...");
        mx.control(MD_MAX72XX::SHUTDOWN, true);  // turn off LEDs
        sleepMessageShown = true;
      }
      break;

    case MODE_SECURE:
      displayEyes(eye_secure);
      break;
  }
}

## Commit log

2026-02-13 Add Arduino sketch for robot eye control
    This file implements an Arduino sketch for controlling a robot's eyes using an LED matrix and servos. It includes modes for different expressions and I2C communication for command handling.
2026-02-13 Add servo control and I2C command handling
    This file implements a servo-controlled robot with multiple modes including normal, dance, and security. It handles I2C commands for controlling the servos and includes functions for motion patterns.
2026-02-13 Fix image filename case in README.md
2026-02-13 Implement web server for ESP32 relay control
    This code sets up a web server on an ESP32 to control a light and a fan via HTTP requests.
2026-02-14 Add I2C robot eye control with servo and LED patterns
    This file implements an I2C-controlled robot eye system with various expressions and servo movements.
2026-02-14 Add ESP32 web server for light and fan control
    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
2026-02-14 Update README to remove Telegram reference
    Removed mention of Telegram from the robot camera description.
2026-02-14 docs: Enhance README with a detailed overview, key features, and a comprehensive Bill of Materials including purchase links.
2026-02-14 docs: Enhance project description and refine the Bill of Materials in README.md.
2026-02-15 Implement HTTP command sending to control ESP32
    Added function to send HTTP requests to control ESP32.
2026-02-16 Create cad

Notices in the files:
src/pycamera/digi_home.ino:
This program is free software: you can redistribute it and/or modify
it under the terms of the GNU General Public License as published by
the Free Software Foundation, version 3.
